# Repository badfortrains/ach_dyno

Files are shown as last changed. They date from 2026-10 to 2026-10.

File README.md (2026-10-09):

# Calf Dyno

An ESP8266 D1 Mini + ADS1220 calf dynamometer with a SvelteKit/TypeScript dashboard, local WebSocket acquisition, Google sign-in, and per-user Firestore history. Firebase project: **ach-dyno**.

## What is implemented

- ADS1220 acquisition at 20 SPS, signed force in newtons, nonblocking tare and known-mass calibration, persisted calibration in LittleFS.
- Password-protected WiFiManager provisioning, a three-minute portal timeout, saved-credential reconnection, and deliberate USB provisioning/reset commands.
- `calf-dyno.local`, WebSocket port 81, HTTP `/status` on port 80, mandatory exact WebSocket Origin validation, and authenticated ArduinoOTA.
- Responsive dashboard with live readings and force chart, leg/exercise labels, start/stop, peak, duration, raw CSV, and paginated history with recent left/right peak comparisons.
- Browser-local run journal, interrupted-run recovery, explicit account saves with stable UUID retries, per-account rules, and a demo simulator whose samples cannot be uploaded.
- `/connectivity` diagnostic page for the HTTPS-to-LAN Chrome compatibility test.

## Wiring

| D1 Mini | ADS1220 / bridge |
| --- | --- |
| 3V3 | DVDD, AVDD, REFP0, cell E+ |
| GND | DGND, AGND, CLK, REFN0, cell E− |
| D1 (GPIO5) | CS |
| D2 (GPIO4) | Dedicated DRDY |
| D5 (GPIO14) | SCLK |
| D6 (GPIO12) | DOUT/MISO |
| D7 (GPIO13) | DIN/MOSI |

Cell S+ connects to AIN0, S− to AIN1. AIN2/AIN3 are unused. CLK grounded selects the internal oscillator. Use a shared ground and 3.3 V logic.

The existing bench configuration is preserved: SPI mode 1 at 1 MHz, gain 128 with PGA enabled, 20 SPS continuous conversion, external REFP0/REFN0 reference, simultaneous 50/60 Hz rejection. Register readback is `0E 04 50 00`. See the [TI ADS1220 datasheet](https://www.ti.com/lit/ds/symlink/ads1220.pdf).

## Firmware setup

Install PlatformIO. Its VS Code extension includes the `pio` CLI. On this Mac it is available at `/Users/suzanna/.platformio/penv/bin/pio` if not on PATH.

1. Copy `platformio.private.ini.example` to `platformio.private.ini`. Set your own OTA password. Optionally set an 8–63 character setup AP password. The real file and generated headers are git-ignored. You can instead supply `DYNO_OTA_PASSWORD`, `DYNO_SETUP_PASSWORD`, and `DYNO_EXTRA_ORIGINS` environment variables.
2. Build and flash the initial firmware using USB:

   ```sh
   pio run -e d1_mini
   pio run -e d1_mini -t upload
   pio device monitor -e d1_mini
   ```

3. On first boot, connect your phone/computer to **CalfDyno-Setup**. If you did not configure an AP password, firmware generates a random password and prints it over USB. Open the captive portal or `http://192.168.4.1`, select your Wi-Fi network, and enter its password.
4. The portal closes after a successful configuration or three minutes. Send `wifi` over USB to reopen it, including when already connected. Stored Wi-Fi credentials are retained through ordinary outages and timeout. Send `wifi-reset CONFIRM` to deliberately erase them and reopen setup.
5. A brand-new device may report that LittleFS is unavailable. Send `fs-init CONFIRM` once over USB to initialize the calibration filesystem. Firmware does **not** automatically format a filesystem that fails to mount. Until initialized, calibration works in RAM and reports that it could not be saved to flash.
6. Unload the sensor in its fixture and send `t` (or use **Zero sensor** in the dashboard). Hold still for about one second while 20 readings are averaged. Apply a known mass and send `c 5.0`, replacing 5.0 with your mass in kg (or use the dashboard calibration controls). The applied force must follow the sensor axis; account for any lever/pulley ratio.

If the dashboard reports **updated in RAM only / flash save failed** on a newly flashed device, keep it powered so its current calibration is retained, connect USB, open `pio device monitor -b 115200`, and send `fs-init CONFIRM` followed by Enter. Expect **Calibration filesystem initialized and current calibration saved.** This command formats the calibration filesystem (erasing any old calibration file), then saves the calibration currently in RAM; it does not reset Wi-Fi credentials. If connecting USB or opening the monitor restarts the device, repeat tare and calibration after initializing storage. After success, power-cycle, reconnect, and confirm the device still reports calibrated. If initialization or saving fails again, retain the exact USB error for diagnosis; repeatedly formatting is not a fix for a write or hardware failure.

Calibration accepts either bridge polarity, rejects saturation and tiny signals, and preserves the slope when taring again. Loaded readings are positive in the calibrated direction; opposite loads are negative. Calibration survives resets once the filesystem is initialized. Re-tare with the fixture unloaded before a session.

Serial commands at **115200 baud**, followed by Enter:

| Command | Action |
| --- | --- |
| `h` | Show help |
| `t` | Tare unloaded cell |
| `c 5.0` | Calibrate using a known 5 kg mass |
| `r` | Retry ADC initialization after fixing wiring |
| `wifi` | Temporarily reopen Wi-Fi provisioning |
| `wifi-reset CONFIRM` | Erase saved Wi-Fi credentials and reopen provisioning |
| `fs-init CONFIRM` | Format the calibration filesystem and save current calibration |

### OTA

Both USB and OTA environments build the same firmware. OTA is disabled when no private password is configured. To enable it initially, configure the password and flash over USB. Then:

```sh
pio run -e d1_mini_ota -t upload
# mDNS fallback:
pio run -e d1_mini_ota -t upload --upload-port 192.168.1.42
```

The build script supplies the same password to firmware and espota. The hostname is `calf-dyno`; mDNS is initialized once and shared with OTA. Acquisition stops on update start; a successful update reboots automatically. If the upload fails, acquisition is reinitialized. USB flashing remains the recovery path. Use OTA only on your trusted LAN; do not forward device ports to the internet. Changing the OTA password requires uploading with the **old** password (or flashing once over USB with the new configuration).

## Dashboard development

Use **Node.js 24.12 or later** and npm:

```sh
cd web
npm ci
npm run dev
```

Open `http://localhost:5173`. Click **Try demo** to test charting, recording, history recovery, and CSV without hardware or sign-in. Click **Use device** to return to real acquisition, then **Connect device**. Supply `calf-dyno.local` or a private IPv4 address. Connect is always initiated by the user; dropped connections retry with bounded exponential delays.

Firebase web configuration is exported from `web/config.ts`; it identifies the Firebase project and is not an OTA/Wi-Fi secret. Browser-only Firebase initialization happens after mounting. The app is a client-rendered SvelteKit SPA using the static adapter; production output is `web/build`.

### Formatting

The dashboard uses [Prettier](https://prettier.io/docs/cli) with [the Svelte plugin](https://github.com/sveltejs/prettier-plugin-svelte) to format Svelte, TypeScript, HTML, CSS, and JSON consistently. Run from the repository root:

```sh
npm --prefix web run format       # Rewrite web source and configuration files
npm --prefix web run format:check # Check formatting without changing files
```

The shared settings are in `web/.prettierrc.json`; generated output, dependencies, test artifacts, environment files, and the generated lockfile are excluded in `web/.prettierignore`. Editor integrations can use these same project settings.

### Run workflow and recovery

1. Connect, calibrate if needed, and zero the unloaded sensor.
2. Measure from the hinge pivot axis to the **center of the dowel under the ball of your foot**, enter that distance in inches, select a leg/exercise, and start recording. The heel aligns with the pivot; pivot-to-heel distance is not the foot lever arm.
3. Stop to review the trace, then export CSV or click **Save** after signing in.
4. Select a history row to inspect its raw trace. History loads 50 runs at a time; use **Load earlier runs** for more.

### Hinged pedal and foot force

The pivot-to-S-beam attachment distance is **13.25 inches**. With the pedal still and both forces vertical, torque balance gives `footForceN = cellForceN × 13.25 / pivotToDowelIn`. For example, a 100 N cell reading with the dowel 6.625 inches from the pivot means 200 N applied at the dowel. This measures force at the ball of the foot, not internal Achilles tendon force. The calculation assumes negligible hinge friction, no contact with a pedal stop, and heel load applied at the hinge axis. Keep the cell aligned vertically and pressure downward at the dowel. See [OpenStax on static equilibrium and torque](https://openstax.org/books/university-physics-volume-1/pages/12-1-conditions-for-static-equilibrium).

The dashboard requires a positive pivot-to-dowel distance no greater than 13.25 inches before recording device runs. It remembers the last distance in this browser, locks it during recording, and saves a snapshot with each run. Live force, recorded samples, peaks, and charts use calculated **foot force**; the live panel also shows cell tension. Moving the dowel clears the rolling live trace, and previously recorded runs retain their original geometry. Older runs without geometry remain labeled **cell force** and are excluded from the latest-foot-force comparisons.

**Body weight (kg)** is optional. Leave it blank to record force and ankle torque without normalization, or enter a positive value up to 1000 kg. Weight is locked during recording and saved as optional `bodyMassKg` metadata with the run, including local recovery checkpoints and cloud saves. Review and history use that run's saved weight, so changing the input later does not alter previous results.

Assuming the ankle joint is centered on the pedal pivot and foot force is perpendicular to the lever arm, `ankleTorqueNm = footForceN × pivotToDowelIn × 0.0254`. Live and peak torque are displayed in **N·m**, and `ankleTorqueNm / bodyMassKg` in **N·m/kg** when weight is supplied. History and CSV exports also include the saved weight and torque values. Runs with no weight show a dash for torque per kg; older runs with no lever geometry show a dash for torque. Torque is derived from the saved force and geometry, rather than storing a second copy of every sample. Demo force remains simulated foot force and can use an entered distance for simulated torque.

To calibrate the assembled pedal, zero with the pedal and dowel installed and no foot or added mass. Rest a stable known mass at a measured position on the pedal, enter its actual mass and **pivot-to-calibration-load distance**, then calibrate. **Use current dowel distance** fills that distance when the mass is centered on the dowel. The UI sends `massKg × calibrationLoadDistanceIn / 13.25` to the existing firmware, so firmware force stays cell tension. For a load applied directly to the S-beam, use 13.25 inches. A previous calibration made with a mass on the pedal at a different distance needs repeating with its correct position before using this conversion.

Deploy **Hosting and Firestore rules together** for this UI (`firebase deploy --only firestore:rules,hosting --project ach-dyno`); firmware does not need updating. New corrected runs use cloud schema 2 with `geometry: { cellDistanceIn: 13.25, footDistanceIn: <measurement> }`. Schema 1 runs remain readable and retryable. CSV includes force basis and both distances alongside the samples, so exports distinguish foot, cell, and simulated forces.

Every completed run is written to IndexedDB **before** any cloud save. Recording checkpoints commit about once per second. A browser crash/power loss recovers the last committed checkpoint; the newest approximately one second may not have committed. Normal stop, connection loss, sample gap, restart, sensor fault, calibration change, account change, or backgrounding the page finalize the samples already received. No missing samples are invented or interpolated in stored data.

Recordings stop at **6,000 samples or five minutes**, whichever comes first. At the default 20 Hz this is about five minutes. This cap, compact cloud maps, and an index exemption keep normal documents comfortably below Firestore's 1 MiB limit. The observed sample rate is computed from device timestamps. Millisecond and sequence wraparound are supported. Chart display decimation preserves peaks and does not reduce stored samples.

Unsaved signed-in runs belong to that account. Anonymous runs can be explicitly saved after signing in; ownership is assigned locally before the cloud attempt. A retry uses the same run UUID and data, preventing duplicate documents. Network/rule failures leave the local run and its CSV available. Demo data remains local. Clearing browser site data removes local backups; successful cloud saves remain in your account. Run recording is disabled if local backup storage is unavailable.

## Firebase setup and deployment

In the [Firebase console for ach-dyno](https://console.firebase.google.com/project/ach-dyno/overview):

1. Enable **Authentication → Google** and choose a support email.
2. Authorize `ach-dyno.web.app`, `ach-dyno.firebaseapp.com`, and `localhost` for local sign-in. New Firebase projects may require adding localhost explicitly. For custom domains, authorize those too.
3. Create a **Cloud Firestore** database on the Spark plan if one does not exist. Deploy the included rules before using cloud saves.
4. Log in to Firebase CLI and deploy from the repository root:

   ```sh
   firebase login
   firebase deploy --only firestore,hosting --project ach-dyno
   ```

The Hosting predeploy hook checks and builds the dashboard. Hosting serves `web/build`, rewrites SPA routes to `index.html`, and caches hashed assets. `/users/{uid}/runs/{runId}` is accessible only to its owner. Completed cloud documents are immutable; identical retries and owner deletes are allowed. Samples are excluded from indexing.

Cloud sample representation differs slightly from the design because [Firestore Standard edition does not support an array containing another array](https://firebase.google.com/docs/firestore/manage-data/data-types):

```json
{
  "schemaVersion": 1,
  "timestamp": "2026-10-08T15:30:00.000Z",
  "leg": "left",
  "exercise": "seated_plantarflexion",
  "durationMs": 50,
  "sampleRateHz": 20,
  "peakForceN": 15,
  "source": "device",
  "stopReason": "Stopped by user",
  "samples": [{ "t": 0, "f": 0 }, { "t": 50, "f": 15 }]
}
```

Local samples and CSV use elapsed milliseconds and newtons, preserving the original `[time, force]` semantics. Rules enforce ownership, field/schema bounds, sample count, and endpoint sample shapes. Firestore Rules cannot loop over every list item; the client validates every sample when saving/loading. The rules do not certify sensor accuracy or clinical validity.

### HTTPS and Chrome connectivity acceptance

Visit `https://ach-dyno.web.app/connectivity` after deployment and test **both desktop Chrome and Android Chrome with the real device**. Verify HTTP status, WebSocket connection, incoming samples, hostname/IP fallback, and reconnect after power interruption.

[Chrome Local Network Access documentation](https://developer.chrome.com/blog/local-network-access) describes permission-gated local HTTP access and mixed-content exemptions, but still lists WebSockets as an integration limitation. Support is browser/version-dependent: a successful HTTP permission probe does **not** prove that an HTTPS page can open `ws://`. The Connect flow probes `/status` to request permission, then attempts the socket and surfaces connection diagnostics. It does not disable browser security or add a separate cloud relay. If your Chrome version blocks the socket, use the local development dashboard for acquisition until a compatible version is available.

Firmware allows exact origins `https://ach-dyno.web.app`, `https://ach-dyno.firebaseapp.com`, and localhost/127.0.0.1 on ports 5173/4173. Missing Origin, `null`, and other sites are rejected at the handshake. Firebase preview-channel/custom-domain origins and local LAN development origins must be added as comma-separated `extra_origins` in `platformio.private.ini`, then firmware must be rebuilt/flashed. This check protects browser access; it is not authentication against native software on your trusted LAN.

## Protocol

Server pushes JSON text frames:

```json
{"type":"sample","bootId":123,"seq":42,"ms":2100,"raw":125000,"forceN":15.25}
```

`ms` is device uptime (uint32), not wall-clock time; `bootId` changes on reboot. `seq` counts ADC samples. `forceN` is `null` before calibration. Status frames arrive on connect and approximately every two seconds and include `protocol: 1`, ADC/calibration/busy/OTA state, IP, and nominal sample rate. Saturation sends an error instead of a valid sample.

Client commands: `{"type":"status"}`, `{"type":"tare","id":"uuid"}`, or `{"type":"calibrate","id":"uuid","massKg":5}`. Calibration/tare responses are `{"type":"ack","id":"uuid","ok":true,"message":"..."}` after averaging. Operations broadcast busy status to all connected dashboards so another browser's calibration cannot silently alter an ongoing run.

## Validation

```sh
pio run -e d1_mini -e d1_mini_ota
cd web
npm run check
npm test
npm run build
npm run test:e2e
cd ..
firebase emulators:exec --project demo-calf-dyno --only firestore 'npm --prefix web run test:rules'
```

The rule tests require Java 21+ and use a `demo-` emulator project, never production. On this Mac, Android Studio's Java runtime is available at `/Applications/Android Studio.app/Contents/jbr/Contents/Home/bin`.

Playwright tests cover desktop/mobile demo recording, CSV, reload recovery, interrupted recording recovery, connection input validation, and simulated device tare/disconnect/reconnection. The config uses installed macOS Google Chrome; on another machine set the executable path or use Playwright's Chromium. Browser layout simulation is not a substitute for physical Android/ESP8266 compatibility testing.

## Hardware troubleshooting

- Wrong register readback: check power, shared ground, CS, SCLK, DIN/MOSI, DOUT/MISO. Expected `0E 04 50 00`.
- DRDY timeout: check dedicated DRDY → D2 and CLK → GND. Fix wiring, then send `r`.
- Saturation: check bridge/reference wiring and applied load. At gain 128 and 3.3 V reference, the differential range is about ±25.8 mV.
- Tiny calibration signal: check bridge leads and mechanical loading; calibration rejects changes below 100 counts.
- Wi-Fi unavailable: firmware retries saved credentials every 15 seconds without erasing them. Send `wifi` to reconfigure deliberately.
- Cloud save denied: check Google authentication and deploy `firestore.rules`. Local run remains available for retry/export.

Physical sensor calibration, real provisioning/reconnection, an authenticated wireless update, production Google sign-in/cloud saves, and HTTPS-to-LAN connectivity on desktop and Android must be verified on the actual hardware/accounts. The implementation and automated checks can be validated locally without flashing or deploying.

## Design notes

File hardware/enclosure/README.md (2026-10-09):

# Calf Dyno snap enclosure — first-fit prototype

Created in Fusion for the soldered D1 mini + ADS1220 + load-cell assembly. Hardware dimensions were not supplied: this is an adjustable, generous-clearance prototype, not a verified board-specific fit.

## Files

- `calf_dyno_enclosure.f3d`: editable Fusion design with two components, named features and user parameters; lid in assembled position.
- `base.stl` and `lid.stl`: millimetres, each placed flat at Z=0 in the intended print orientation. Import as separate objects in Bambu Studio.
- `calf_dyno_enclosure.step`: assembled solid CAD interchange file.
- `enclosure_preview.png`: initial overview of the base and upside-down lid; the PLA revision lengthens the tabs by 2 mm and lowers the matching windows by 2 mm.
- `create_enclosure.py`: Fusion Python script recreating the parametric design in a new document.
- `base_raw.stl`, `lid_raw.stl`: intermediate Fusion exports, in assembly coordinates. Use `base.stl` and `lid.stl` for printing.
- `prepare_prints.py`: converts the default-size raw meshes to print orientation and validates their topology. Its orientation offsets match this delivered 90 × 65 × 34 mm design; update offsets for resized exports, or orient resized parts in the slicer.

## Dimensions and construction

| Item | Default |
|---|---:|
| Assembled exterior | 90 × 65 × 34 mm |
| Nominal clear cavity | 86 × 61 × 30 mm |
| Wall / floor / lid plate | 2 / 2 / 2 mm |
| USB-C plug opening | 16 mm wide × 10 mm high |
| USB opening bottom | 4 mm above exterior bottom (2 mm above interior floor) |
| Cable notch | 7 mm wide × 7 mm deep, rounded bottom |
| Lid fit clearance | 0.30 mm per side |
| Snap tabs | Four, 14 mm long × 8 mm wide × 1.2 mm thick |
| Snap-hook projection | 0.55 mm from stem; nominal wall engagement 0.25 mm |
| Snap root fillet | 0.8 mm |

The cavity size is the bounding clear envelope: lid clips and corner guides occupy small regions near the walls, and a low cable-tie bridge occupies space near the cable end. Leave wiring clear of those features.

The USB opening is centered on one short wall. The load-cell cable drops into a U-shaped notch on the opposite short wall; the lid closes its top. Nothing needs to be threaded over the already-soldered cable. The notch is not a compression gland or seal.

The floor is flat so the boards can be secured with insulating foam tape or removable adhesive mounts after positioning the D1 mini's USB-C socket at the opening. There are no assumed mounting-hole patterns or board-specific standoffs. Check the socket height and USB plug insertion depth with the actual board and plug before permanently mounting anything.

A small internal bridge accepts a narrow zip tie for cable strain relief. Route the cable with a gentle bend and secure its jacket, avoiding tension on the solder joints. This enclosure is not a load-bearing part of the dynamometer.

## First print on a Bambu Lab P1S

Suggested starting settings, assuming the standard 0.4 mm nozzle:

- 0.20 mm layer height, 4 wall loops, 5 top/bottom layers, 15–20% infill.
- Use the matching filament preset in Bambu Studio.
- Base: floor on plate, open cavity up.
- Lid: broad outside face on plate, clips pointing up; the provided STL is already flipped.
- Start with supports off. Inspect bridging in the slice preview: the USB opening spans 16 mm, snap windows about 8.6 mm, and tie tunnel 4 mm. Adjust bridge settings or add targeted support if the chosen material/profile needs it; avoid support inside the snap clearances.
- Use PLA as requested. The PLA revision uses 14 mm flexible tabs and 0.25 mm nominal hook engagement to reduce the deflection needed to latch. Test the empty enclosure first; clip life has not been physically tested.

Fit and snap durability have not been physically tested. Test the lid on the empty box first. Press progressively near each tab rather than forcing the center. Release tabs by pushing them inward through the side windows with a small blunt tool while lifting the adjacent lid edge.

## Adjust in Fusion

Open Modify → Change Parameters. Main parameters are `inside_length`, `inside_width`, `inside_height`, `usb_width`, `usb_height`, `usb_bottom`, `usb_y`, `cable_width`, `cable_depth` and `fit_clearance`. Exterior dimensions are derived automatically. Sizes are in mm.

For a tight snap, increasing `fit_clearance` from 0.30 to 0.35 mm reduces engagement; keep it below `snap_projection` or the hooks will cease to latch. Increasing clearance also loosens the corner guides. Change by small amounts and test. The cable-seat radius is linked to cable width; retain enough notch depth for that radius. Arbitrarily large parameter changes may require feature edits.

Hide the lid component to inspect the cavity. After editing, export both components again and orient the lid outside-face down in Bambu Studio. Do not scale the entire STL to resize the enclosure: that changes wall thickness, port size and snap clearances together.

## Checks performed

PLA revision: changed snap length 12→14 mm and hook projection 0.65→0.55 mm. Recomputed with no warnings, rechecked zero assembled interference, and regenerated/validated both print meshes. The lid print height is now 16 mm. The dimensional resize test below was performed on the initial revision.

- Two solid bodies, one per component; all 64 timeline items healthy.
- No assembled solid interference (coincident contact faces excluded).
- Successfully resized interior length 86→96 mm, width 61→66 mm, height 30→34 mm, USB width 16→18 mm and cable width 7→8 mm, then restored defaults; no feature warnings.
- Both print meshes are closed, manifold, connected, positive-volume meshes at Z=0. Full measurements are in `mesh_validation.json`.
- Inspected the Fusion preview. Physical electronics fit, cable clearance and snap fatigue remain first-print checks.

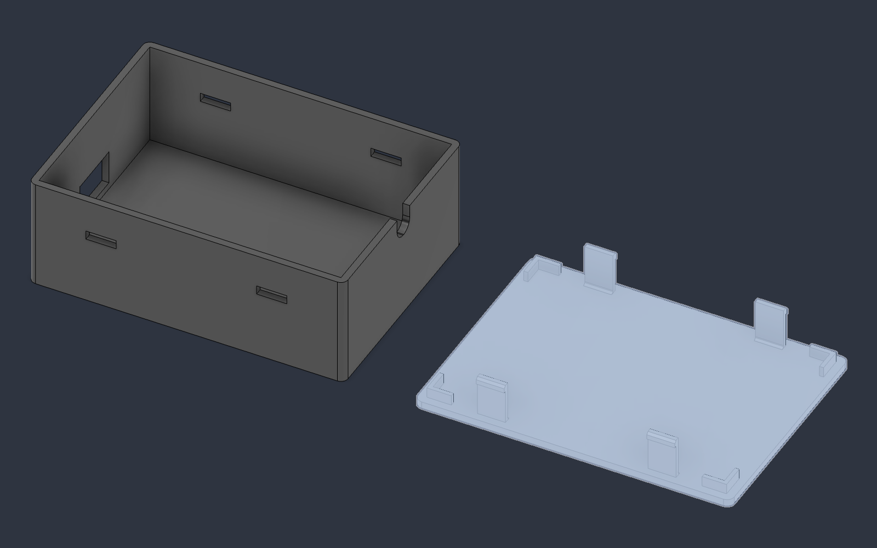
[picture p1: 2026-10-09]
hardware/enclosure/enclosure_preview.png

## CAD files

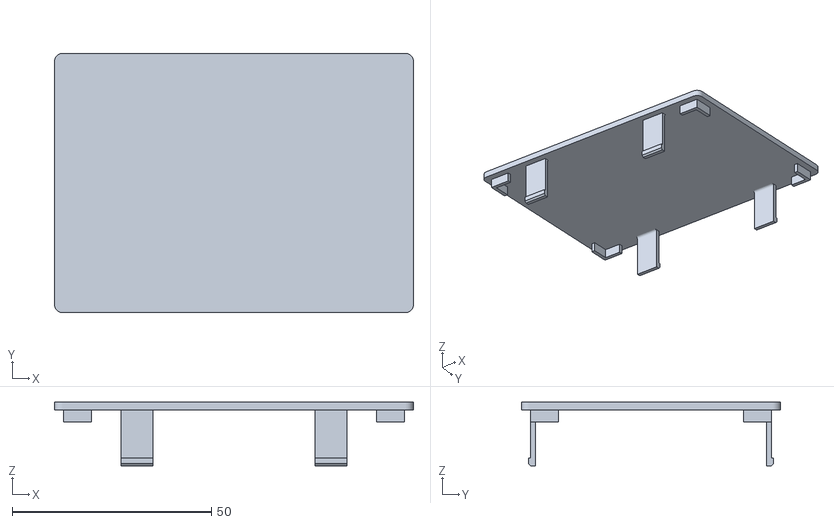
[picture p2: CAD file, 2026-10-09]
hardware/enclosure/lid_raw.stl
90.0 x 65.0 x 16.0

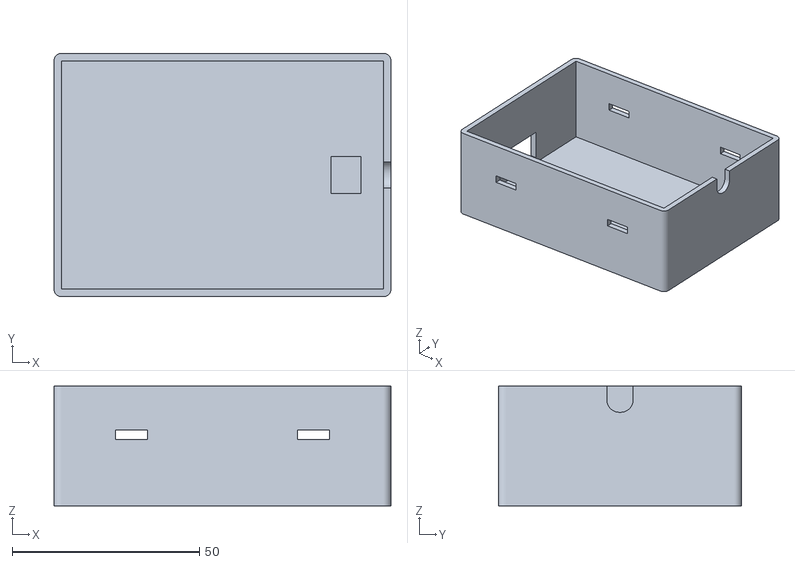
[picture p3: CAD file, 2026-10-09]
hardware/enclosure/base_raw.stl
90.0 x 65.0 x 32.0

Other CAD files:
hardware/enclosure/calf_dyno_enclosure.step
hardware/enclosure/lid.stl
hardware/enclosure/base.stl
hardware/enclosure/calf_dyno_enclosure.f3d

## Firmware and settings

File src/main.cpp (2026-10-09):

#include <Arduino.h>
#include <ArduinoJson.h>
#include <ArduinoOTA.h>
#include <ESP8266WiFi.h>
#include <ESP8266WebServer.h>
#include <ESP8266mDNS.h>
#include <LittleFS.h>
#include <SPI.h>
#include <WebSocketsServer.h>
#include <WiFiManager.h>
#include <math.h>
#include "dyno_secrets.h"

namespace {
constexpr uint8_t CS_PIN = D1, DRDY_PIN = D2;
constexpr uint32_t ADC_TIMEOUT_MS = 1000, PORTAL_TIMEOUT_MS = 180000;
constexpr uint8_t AVERAGE_SAMPLES = 20;
// 20 SPS, gain 128, continuous, external REFP0/REFN0, 50/60 Hz rejection.
constexpr uint8_t CONFIG[] = {0x0E, 0x04, 0x50, 0x00};
const SPISettings ADC_SPI(1000000, MSBFIRST, SPI_MODE1);
ESP8266WebServer http(80);
WebSocketsServer socket(81);
WiFiManager wifiManager;
bool adcReady = false, calibrated = false, hasTare = false;
bool fsReady = false, networkReady = false, otaActive = false, portalActive = false;
double tareCounts = 0, countsPerKg = 0;
uint32_t lastSampleMs = 0, sequence = 0, lastStatusMs = 0;
uint32_t portalStartedMs = 0, lastReconnectMs = 0, bootId = 0;
String setupPassword;
char serialBuffer[96];
size_t serialLength = 0;
bool serialOverflow = false;
// Calibration is asynchronous: network and OTA handlers keep running.
enum class Operation { None, Tare, Calibrate };
Operation operation = Operation::None;
int64_t operationSum = 0;
uint8_t operationCount = 0;
double calibrationMass = 0;
int operationClient = -1;
String operationId;
const char *calibrationSaveError = "Sensor updated in RAM only; flash save failed.";

void selectAdc() {
  SPI.beginTransaction(ADC_SPI);
  digitalWrite(CS_PIN, LOW);
  delayMicroseconds(2);
}
void deselectAdc() {
  delayMicroseconds(2);
  digitalWrite(CS_PIN, HIGH);
  SPI.endTransaction();
}
void adcCommand(uint8_t command) {
  selectAdc(); SPI.transfer(command); deselectAdc();
}
bool initializeAdc() {
  adcCommand(0x06); delay(2);
  selectAdc(); SPI.transfer(0x43);
  for (uint8_t value : CONFIG) SPI.transfer(value);
  deselectAdc();
  selectAdc(); SPI.transfer(0x23);
  bool matches = true;
  Serial.print(F("ADS1220 registers:"));
  for (uint8_t expected : CONFIG) {
    uint8_t actual = SPI.transfer(0);
    Serial.printf(" %02X", actual);
    matches &= actual == expected;
  }
  deselectAdc(); Serial.println();
  if (!matches) {
    Serial.println(F("ADC register mismatch: expected 0E 04 50 00. Check wiring; send r."));
    return false;
  }
  adcCommand(0x08); lastSampleMs = millis();
  return true;
}
int32_t readSample() {
  selectAdc(); SPI.transfer(0x10);
  uint32_t value = static_cast<uint32_t>(SPI.transfer(0)) << 16;
  value |= static_cast<uint32_t>(SPI.transfer(0)) << 8;
  value |= SPI.transfer(0);
  deselectAdc(); lastSampleMs = millis();
  return (value & 0x800000UL) ? static_cast<int32_t>(value) - 16777216L : static_cast<int32_t>(value);
}
bool originAllowed(const String &origin) {
  if (origin == "https://ach-dyno.web.app" || origin == "https://ach-dyno.firebaseapp.com" ||
      origin == "http://localhost:5173" || origin == "http://127.0.0.1:5173" ||
      origin == "http://localhost:4173" || origin == "http://127.0.0.1:4173") return true;
  String extra(DYNO_EXTRA_ORIGINS);
  int start = 0;
  while (start < static_cast<int>(extra.length())) {
    int end = extra.indexOf(',', start);
    if (end < 0) end = extra.length();
    String candidate = extra.substring(start, end); candidate.trim();
    if (candidate.length() && origin == candidate) return true;
    start = end + 1;
  }
  return false;
}
String statusJson() {
  JsonDocument doc;
  doc["type"] = "status"; doc["protocol"] = 1;
  doc["bootId"] = bootId; doc["hostname"] = "calf-dyno";
  doc["ip"] = WiFi.localIP().toString(); doc["uptimeMs"] = millis();
  doc["adcReady"] = adcReady; doc["calibrated"] = calibrated;
  doc["hasTare"] = hasTare; doc["busy"] = operation != Operation::None;
  doc["otaActive"] = otaActive; doc["otaEnabled"] = strlen(DYNO_OTA_PASSWORD) > 0;
  doc["sampleRateHz"] = 20; doc["freeHeap"] = ESP.getFreeHeap();
  String output; serializeJson(doc, output); return output;
}
void broadcastStatus() {
  if (networkReady) { String output = statusJson(); socket.broadcastTXT(output); }
}
void reply(int client, const String &id, bool ok, const char *message) {
  Serial.println(message);
  if (client < 0 || !networkReady || !socket.clientIsConnected(client)) return;
  JsonDocument doc; doc["type"] = "ack"; doc["id"] = id;
  doc["ok"] = ok; doc["message"] = message;
  String output; serializeJson(doc, output); socket.sendTXT(client, output);
}
bool saveCalibration() {
  if (!fsReady) {
    calibrationSaveError = "Sensor updated in RAM only; calibration filesystem unavailable. On a new device, send fs-init CONFIRM over USB at 115200 baud to initialize storage and save current calibration.";
    return false;
  }
  JsonDocument doc; doc["version"] = 1; doc["tareCounts"] = tareCounts;
  doc["countsPerKg"] = countsPerKg; doc["hasTare"] = hasTare;
  doc["calibrated"] = calibrated;
  File file = LittleFS.open("/calibration.tmp", "w");
  if (!file) {
    calibrationSaveError = "Sensor updated in RAM only; could not open the calibration file on flash. Check USB logs and filesystem space.";
    return false;
  }
  size_t expected = measureJson(doc);
  size_t written = serializeJson(doc, file);
  file.flush(); file.close();
  if (written != expected) {
    calibrationSaveError = "Sensor updated in RAM only; calibration file write was incomplete. Check USB logs and filesystem space.";
    return false;
  }
  if (!LittleFS.rename("/calibration.tmp", "/calibration.json")) {
    calibrationSaveError = "Sensor updated in RAM only; replacing the calibration file on flash failed. Check USB logs and filesystem space.";
    return false;
  }
  return true;
}
void loadCalibration() {
  if (!fsReady) return;
  File file = LittleFS.open("/calibration.json", "r");
  if (!file) return;
  JsonDocument doc; auto error = deserializeJson(doc, file); file.close();
  if (error || doc["version"] != 1 || !doc["tareCounts"].is<double>() ||
      !doc["countsPerKg"].is<double>()) return;
  double tare = doc["tareCounts"], slope = doc["countsPerKg"];
  if (!isfinite(tare) || fabs(tare) > 8388608 || !isfinite(slope)) return;
  if (doc["calibrated"] == true && fabs(slope) < 0.000001) return;
  tareCounts = tare; countsPerKg = slope;
  hasTare = doc["hasTare"] == true; calibrated = doc["calibrated"] == true && hasTare;
}
void finishOperation(bool ok, const char *message) {
  reply(operationClient, operationId, ok, message);
  operation = Operation::None; operationClient = -1; operationId = "";
  broadcastStatus();
}
void startOperation(Operation next, double mass, int client = -1, String id = "") {
  if (!adcReady || otaActive || operation != Operation::None) {
    reply(client, id, false, "Sensor unavailable or busy."); return;
  }
  if (next == Operation::Calibrate && (!hasTare || !isfinite(mass) || mass <= 0 || mass > 10000)) {
    reply(client, id, false, "Tare first, then specify a positive known mass in kg (up to 10000)."); return;
  }
  operation = next; operationSum = 0; operationCount = 0;
  operationClient = client; operationId = id; calibrationMass = mass;
  adcCommand(0x08); lastSampleMs = millis(); broadcastStatus();
}
void processSample(int32_t sample) {
  ++sequence;
  if (sample >= 8380000L || sample <= -8380000L) {
    if (operation != Operation::None) finishOperation(false, "ADC saturated; calibration cancelled.");
    // Send an explicit fault: never publish a saturated reading as valid force.
    if (networkReady) socket.broadcastTXT("{\"type\":\"error\",\"message\":\"ADC saturated. Check load and bridge wiring.\"}");
    return;
  }
  if (operation != Operation::None) {
    operationSum += sample;
    if (++operationCount == AVERAGE_SAMPLES) {
      double average = static_cast<double>(operationSum) / operationCount;
      if (operation == Operation::Tare) { tareCounts = average; hasTare = true; }
      else {
        double net = average - tareCounts;
        if (fabs(net) < 100) { finishOperation(false, "Calibration signal too small; apply a larger known load."); return; }
        countsPerKg = net / calibrationMass; calibrated = true;
      }
      bool stored = saveCalibration();
      finishOperation(true, stored ? "Sensor updated and saved to flash." : calibrationSaveError);
    }
    return;
  }
  double force = calibrated ? (sample - tareCounts) / countsPerKg * 9.80665 : 0;
  if (networkReady && socket.connectedClients() > 0) {
    JsonDocument doc; doc["type"] = "sample"; doc["bootId"] = bootId;
    doc["seq"] = sequence; doc["ms"] = lastSampleMs; doc["raw"] = sample;
    if (calibrated) doc["forceN"] = force; else doc["forceN"] = nullptr;
    String output; serializeJson(doc, output); socket.broadcastTXT(output);
  }
  if (sequence % 5 == 0) {
    Serial.printf("raw=%ld  net=%.1f", static_cast<long>(sample), sample - tareCounts);
    if (calibrated) Serial.printf("  force=%.2f N", force);
    else Serial.print(F("  uncalibrated"));
    Serial.println();
  }
}
void socketEvent(uint8_t client, WStype_t type, uint8_t *payload, size_t length) {
  if (type == WStype_CONNECTED) { String status = statusJson(); socket.sendTXT(client, status); return; }
  if (type == WStype_DISCONNECTED) {
    // Prevent an asynchronous ACK from reaching a different client reusing this slot.
    if (operationClient == client) operationClient = -1;
    return;
  }
  if (type != WStype_TEXT) return;
  JsonDocument doc;
  if (length > 256 || deserializeJson(doc, payload, length)) { reply(client, "", false, "Invalid JSON command."); return; }
  String command = doc["type"] | ""; String id = doc["id"] | "";
  if (id.length() > 48) { reply(client, "", false, "Command ID too long."); return; }
  if (command == "status") { String status = statusJson(); socket.sendTXT(client, status); }
  else if (command == "tare") startOperation(Operation::Tare, 0, client, id);
  else if (command == "calibrate" && doc["massKg"].is<double>()) startOperation(Operation::Calibrate, doc["massKg"], client, id);
  else reply(client, id, false, "Unknown command; use status, tare, or calibrate with massKg.");
}
void stopNetwork() {
  if (!networkReady) return;
  socket.close(); http.stop(); ArduinoOTA.end(); MDNS.close(); networkReady = false;
}
void startPortal() {
  if (otaActive) return;
  if (operation != Operation::None) finishOperation(false, "Operation cancelled for Wi-Fi provisioning.");
  stopNetwork();
  portalActive = true; portalStartedMs = millis();
  Serial.printf("Connect to CalfDyno-Setup, password: %s (3 minute timeout).\n", setupPassword.c_str());
  wifiManager.startConfigPortal("CalfDyno-Setup", setupPassword.c_str());
}
void startNetwork() {
  if (portalActive) { wifiManager.stopConfigPortal(); portalActive = false; }
  // One mDNS initialization; OTA adds its service to the existing responder.
  MDNS.begin("calf-dyno"); MDNS.addService("http", "tcp", 80); MDNS.addService("ws", "tcp", 81);
  socket.begin(); socket.enableHeartbeat(15000, 3000, 2); http.begin();
  networkReady = true;
  if (strlen(DYNO_OTA_PASSWORD)) {
    ArduinoOTA.setHostname("calf-dyno"); ArduinoOTA.setPassword(DYNO_OTA_PASSWORD);
    ArduinoOTA.begin(false);
    // begin(false) doesn't register the service, so add it ourselves.
    MDNS.enableArduino(8266, true);
  } else Serial.println(F("OTA disabled: configure private ota_password and flash over USB to enable."));
  Serial.printf("Ready: http://%s/status | ws://calf-dyno.local:81\n", WiFi.localIP().toString().c_str());
}
void printHelp() {
  Serial.println(F("Commands: t (tare), c 5.0 (known kg), r (retry ADC), h (help), wifi (open setup), wifi-reset CONFIRM (erase credentials), fs-init CONFIRM (format calibration filesystem)."));
}
void serialCommand(char *command) {
  if (!strcmp(command, "h")) printHelp();
  else if (!strcmp(command, "wifi")) startPortal();
  else if (!strcmp(command, "wifi-reset CONFIRM")) { stopNetwork(); wifiManager.resetSettings(); startPortal(); }
  else if (!strcmp(command, "fs-init CONFIRM")) {
    if (otaActive || operation != Operation::None) { Serial.println(F("Sensor busy; try again later.")); return; }
    LittleFS.end();
    fsReady = LittleFS.format() && LittleFS.begin();
    if (!fsReady) Serial.println(F("Filesystem initialization failed; calibration remains in RAM only."));
    else if (!saveCalibration()) Serial.println(calibrationSaveError);
    else Serial.println(F("Calibration filesystem initialized and current calibration saved."));
  }
  else if (!strcmp(command, "t")) startOperation(Operation::Tare, 0);
  else if (!strcmp(command, "r")) {
    if (operation != Operation::None) finishOperation(false, "Operation cancelled for ADC reset.");
    if (!otaActive) { adcReady = initializeAdc(); broadcastStatus(); }
  } else if (command[0] == 'c' && command[1] == ' ') {
    char *end; double mass = strtod(command + 2, &end);
    while (*end == ' ') ++end;
    if (end == command + 2 || *end || !isfinite(mass) || mass <= 0) Serial.println(F("Use c <positive kg>."));
    else startOperation(Operation::Calibrate, mass);
  } else if (*command) Serial.println(F("Unknown command. Send h."));
}
void pollSerial() {
  while (Serial.available()) {
    char c = Serial.read();
    if (c == '\r' || c == '\n') {
      serialBuffer[serialLength] = 0;
      if (!serialOverflow) serialCommand(serialBuffer); else Serial.println(F("Command too long."));
      serialLength = 0; serialOverflow = false;
    } else if (serialLength < sizeof(serialBuffer) - 1) serialBuffer[serialLength++] = c;
    else serialOverflow = true;
  }
}
}  // namespace

void setup() {
  Serial.begin(115200); delay(300); bootId = ESP.random();
  digitalWrite(CS_PIN, HIGH); pinMode(CS_PIN, OUTPUT); pinMode(DRDY_PIN, INPUT); SPI.begin();
  // Do not format on mount failure: preserve previously saved calibration.
  LittleFSConfig fsConfig; fsConfig.setAutoFormat(false); LittleFS.setConfig(fsConfig);
  fsReady = LittleFS.begin();
  if (!fsReady) {
    // A brand new filesystem can be initialized deliberately via USB, see README.
    Serial.println(F("LittleFS unavailable; calibration will be RAM-only. On a new device, send fs-init CONFIRM to initialize storage and save current calibration."));
  }
  loadCalibration(); adcReady = initializeAdc(); printHelp();
  setupPassword = DYNO_SETUP_PASSWORD;
  if (setupPassword.isEmpty()) {
    char randomPassword[17]; snprintf(randomPassword, sizeof(randomPassword), "%08lx%08lx", static_cast<unsigned long>(ESP.random()), static_cast<unsigned long>(ESP.random()));
    setupPassword = randomPassword;
  }
  http.collectHeaders("Origin", "Access-Control-Request-Headers");
  http.on("/status", []() {
    String origin = http.header("Origin");
    if (origin.length() && !originAllowed(origin)) { http.send(403, "text/plain", "Origin denied"); return; }
    if (origin.length()) { http.sendHeader("Access-Control-Allow-Origin", origin); http.sendHeader("Vary", "Origin"); }
    http.sendHeader("Cache-Control", "no-store");
    if (http.method() == HTTP_OPTIONS) {
      http.sendHeader("Access-Control-Allow-Methods", "GET, OPTIONS");
      http.sendHeader("Access-Control-Allow-Private-Network", "true");
      http.send(204); return;
    }
    if (http.method() != HTTP_GET) { http.send(405); return; }
    http.send(200, "application/json", statusJson());
  });
  http.onNotFound([]() { http.send(404, "text/plain", "Use /status"); });
  static const char *mandatory[] = {"Origin"};
  socket.onValidateHttpHeader([](String name, String value) { return !name.equalsIgnoreCase("Origin") || originAllowed(value); }, mandatory, 1);
  socket.onEvent(socketEvent);
  ArduinoOTA.onStart([]() {
    otaActive = true;
    if (operation != Operation::None) finishOperation(false, "Operation cancelled for firmware update.");
    adcCommand(0x02); broadcastStatus(); socket.disconnect(); LittleFS.end();
    Serial.println(F("OTA update started; measurements stopped."));
  });
  ArduinoOTA.onError([](ota_error_t error) {
    Serial.printf("OTA error %u; restoring acquisition.\n", error);
    otaActive = false; fsReady = LittleFS.begin(); adcReady = initializeAdc(); broadcastStatus();
  });
  WiFi.mode(WIFI_STA); WiFi.setAutoReconnect(true);
  wifiManager.setDebugOutput(false); wifiManager.setConfigPortalBlocking(false);
  wifiManager.setConnectTimeout(15); wifiManager.setBreakAfterConfig(true);
  // Nonblocking WiFiManager ignores its own timeout; loop enforces ours.
  if (WiFi.SSID().length()) { WiFi.begin(); lastReconnectMs = millis(); }
  else startPortal();
}
void loop() {
  pollSerial();
  if (portalActive) {
    wifiManager.process();
    if (!wifiManager.getConfigPortalActive()) {
      portalActive = false; WiFi.mode(WIFI_STA);
    } else if (millis() - portalStartedMs >= PORTAL_TIMEOUT_MS) {
      wifiManager.stopConfigPortal(); portalActive = false; WiFi.mode(WIFI_STA);
      Serial.println(F("Setup timed out; send wifi over USB to reopen. Saved credentials retained."));
    }
  }
  if (!portalActive && WiFi.status() == WL_CONNECTED) {
    if (!networkReady) startNetwork();
    http.handleClient(); socket.loop(); MDNS.update();
    if (strlen(DYNO_OTA_PASSWORD)) ArduinoOTA.handle();
    if (millis() - lastStatusMs >= 2000) { lastStatusMs = millis(); broadcastStatus(); }
  } else {
    stopNetwork();
    if (!portalActive && WiFi.SSID().length() && millis() - lastReconnectMs >= 15000) {
      lastReconnectMs = millis(); WiFi.reconnect();
    }
  }
  if (!otaActive && adcReady) {
    if (digitalRead(DRDY_PIN) == LOW) processSample(readSample());
    else if (millis() - lastSampleMs >= ADC_TIMEOUT_MS) {
      adcReady = false;
      if (operation != Operation::None) finishOperation(false, "DRDY timeout. Check wiring and send r over USB.");
      Serial.println(F("ADC timeout. Check D2/DRDY, CLK to GND, and power; send r.")); broadcastStatus();
    }
  }
  delay(1);
}

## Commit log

2026-10-09 force based on dowel position
    [base.stl, base_raw.stl, calf_dyno_enclosure.f3d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]
2026-10-09 weight and torque
